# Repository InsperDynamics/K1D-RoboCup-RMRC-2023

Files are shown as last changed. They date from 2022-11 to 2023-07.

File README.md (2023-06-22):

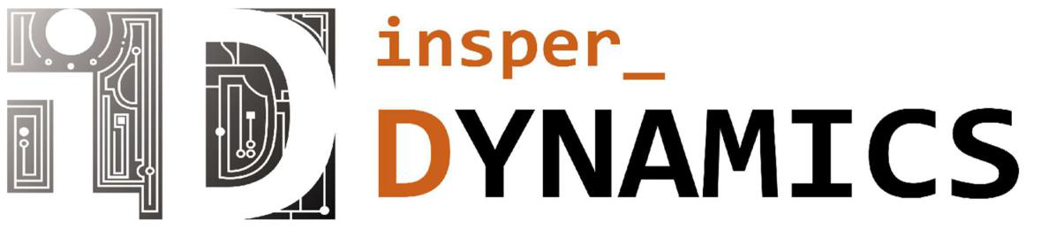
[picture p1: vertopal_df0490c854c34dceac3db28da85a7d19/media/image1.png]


> Team Description Materials\
> Rapidly Manufactured Robot Challenge RoboCup Rescue 2023
>
> Felipe Catapano Emrich Melo, Rafael Eli Katri, Katy Terra, Enricco
> Gemha, Eduardo Mendes Vaz, Paola Friedel

March 2023

 **Abstract**

 The goal of the project presented in this material is the planning,
 construction and testing of a new, semi-autonomous robot suited for
 rescue operations. The robot must be able to traverse heavily uneven
 terrain, inspect the environment and manipulate objects to aid humans
 in dangerous or disaster-related scenarios, where the use of a human
 agent is undesirable or slow.

 It is a major technical overhaul of the project presented by the
 previous team, where more robust mechanical design, manufacturing
 methods, electronics employment and software techniques were used. The
 2023 robot not only takes advantage of previously achieved innovations
 but has improvements in a wide range of aspects that proved to be
 crucial in many scenarios.

 **Introduction**

 The world is constantly evolving, with new and improved solutions
 emerging day by day. A decade ago, self-driving cars were just an
 idea, but now we have cars that are capable of autonomous driving. As
 humans, we are always striving to improve upon existing technology.

 Considering this, RoboCup was established to encourage students in the
 fields of robotics, technology, and AI development to create solutions
 that can benefit humanity.

 One category of the competition is the Rapidly Manufactured Robot
 Challenge, which challenges teams to build smaller and easier to
 produce robots than their Major rescue counterparts, that can assist
 humans in dangerous situations.

 Our team, Insper Dynamics, consisting of five members - Felipe,
 Rafael, Katy, Enrico and Eduardo, are all computer and mechanics
 engineering students from Brazil. With the help of Fabrício Barth, the
 advisor teacher of Insper Dynamics, the team was able to largely
 improve the previous year´s (RoboCup 2022 Thailand) system with the
 use of a simpler and more compact electronic system, aluminum and
 steel parts, flipper tracks, smart servo motors, a web

 interface and algorithm improvements. Our strategies and results are
 detailed in this paper.

 **Structure**

 **Overview**

 The new robot consists of three modular layers. The bottom layer
 contains

two aluminum compartment chassis connected by two bearings and a
pivoting,

machined shaft, as well as four individual flipping track mechanisms.
The middle

 layer is a box with adjustable height, and the top layer has a
 manipulator arm and sensors.

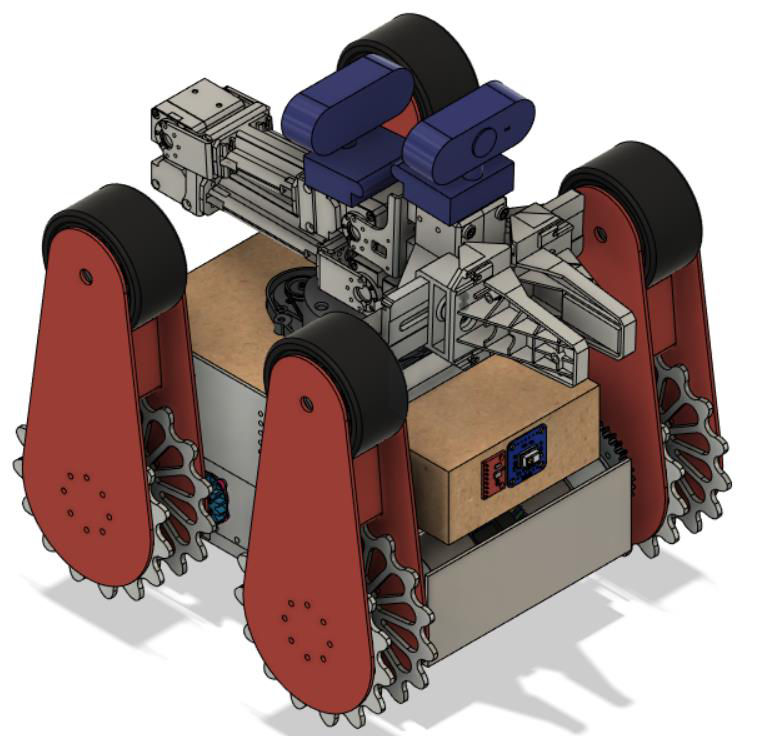
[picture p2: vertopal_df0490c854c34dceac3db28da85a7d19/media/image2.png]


*Figure 1 Isometric view of the robot*

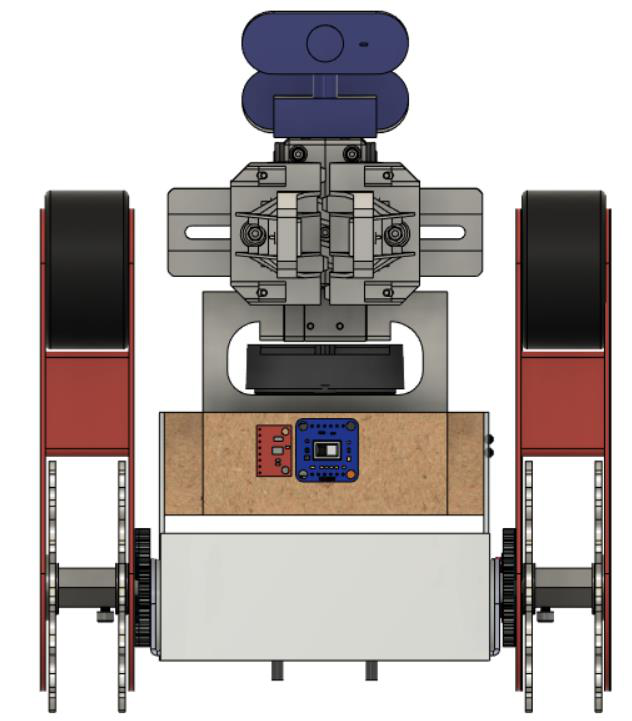
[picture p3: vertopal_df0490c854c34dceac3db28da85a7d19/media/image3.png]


*Figure 2 Frontal view of the robot*

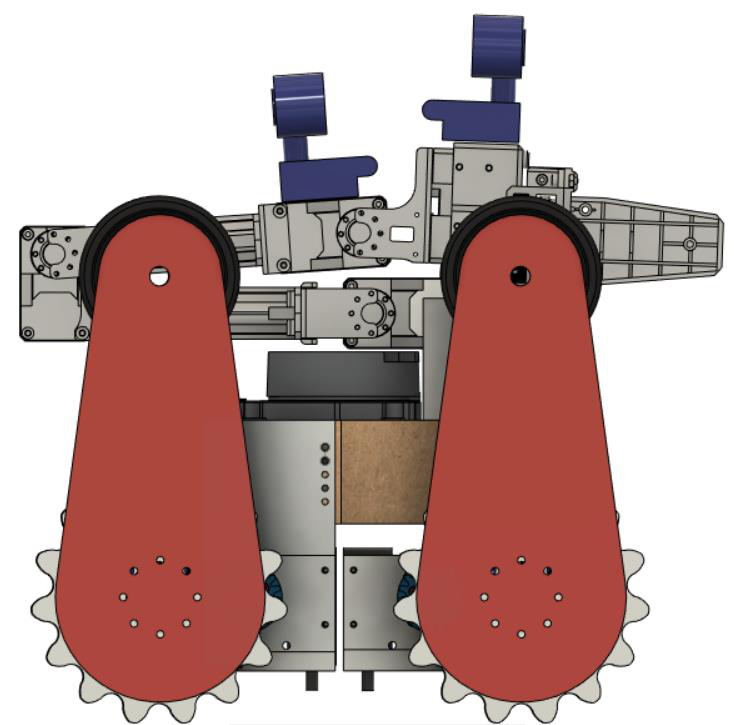
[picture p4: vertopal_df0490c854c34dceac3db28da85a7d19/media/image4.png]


*Figure 3 Side view of the robot*

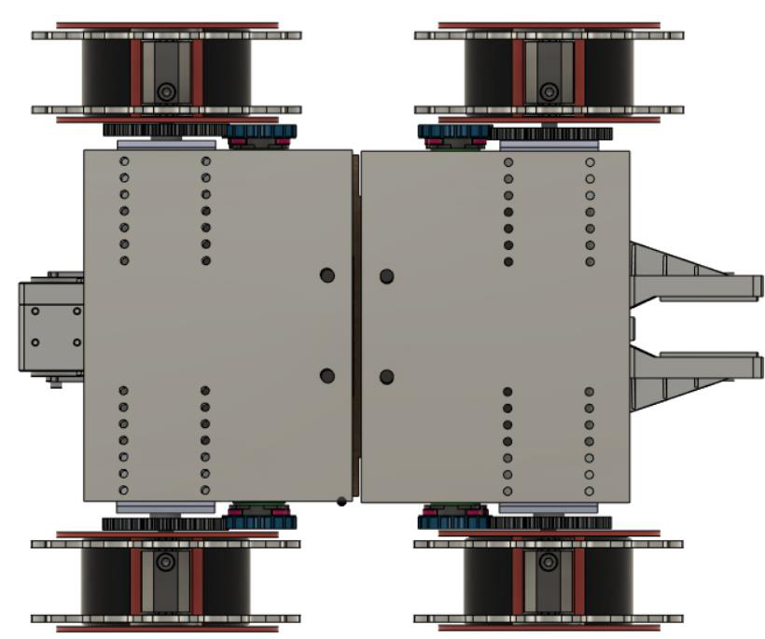
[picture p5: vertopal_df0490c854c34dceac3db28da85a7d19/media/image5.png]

*Figure 4 Bottom vertical view of the robot*

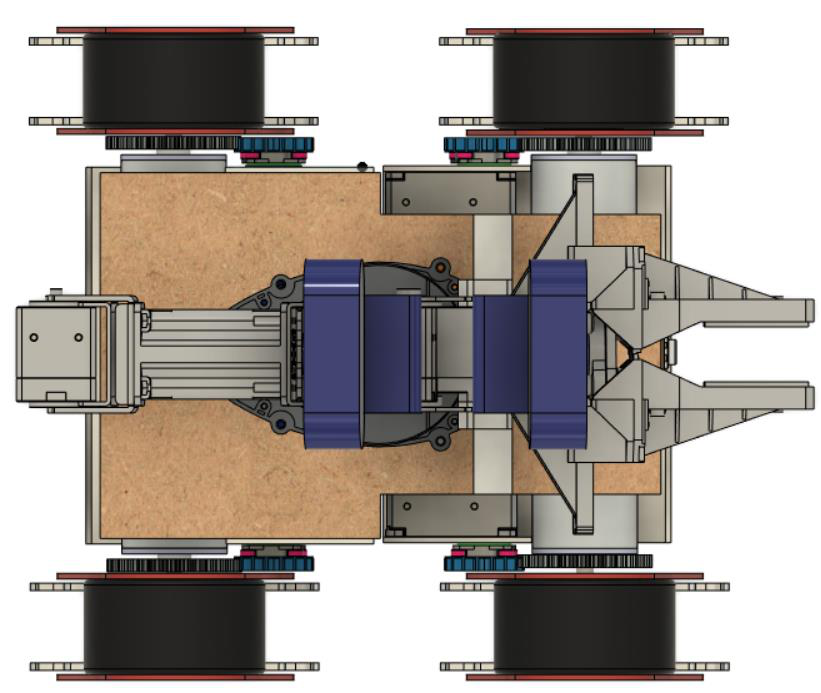
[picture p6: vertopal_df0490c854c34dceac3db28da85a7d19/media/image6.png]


*Figure 5 Top vertical view of the robot.*

 **Metal chassis**

 With the use of a laser or plasma cutter, two low-tolerance parts are extracted from raw material and bent to form housings for two driving DC motors with high torque, two Robotis Dynamixel smart servos, and a bearing holder. This solution is more robust than previous 3D-printed plastic designs, not only due to a better use of available space for mechanical resistance redundancy, but also because of the new material´s tenacity. It also includes a new protection wall against sand, gravel and other sediments that can be harmful to the system.

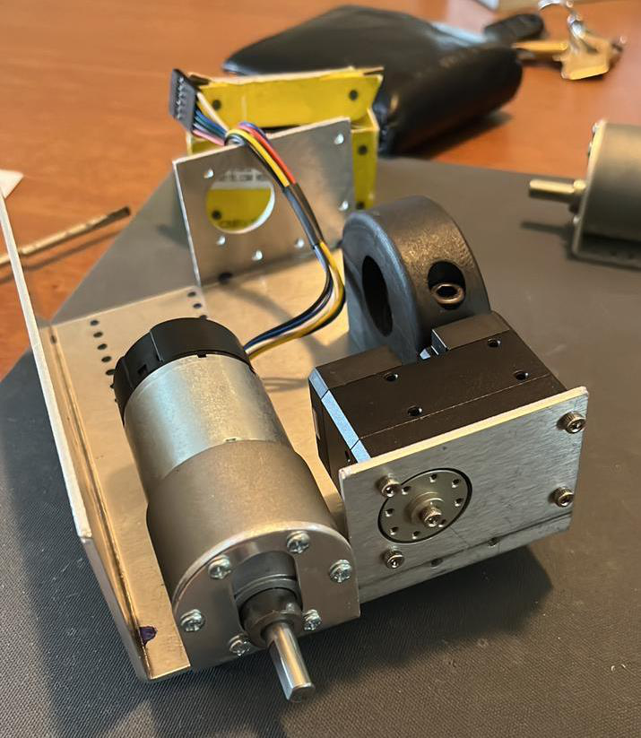
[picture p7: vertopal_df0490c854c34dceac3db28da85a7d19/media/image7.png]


*Figure 6 Half assembly of a chassis compartment*

 The front and back compartments are free to twist around the axis of the central bearings, to act as a passive suspension and allow the robot to always have at least four points of contact with the ground. This was already achieved in the previous project, however this time, a double bearing setup was used with a custom machined shaft. Since a large portion of force is exerted on this central arrangement, this is required to prevent structural failure.

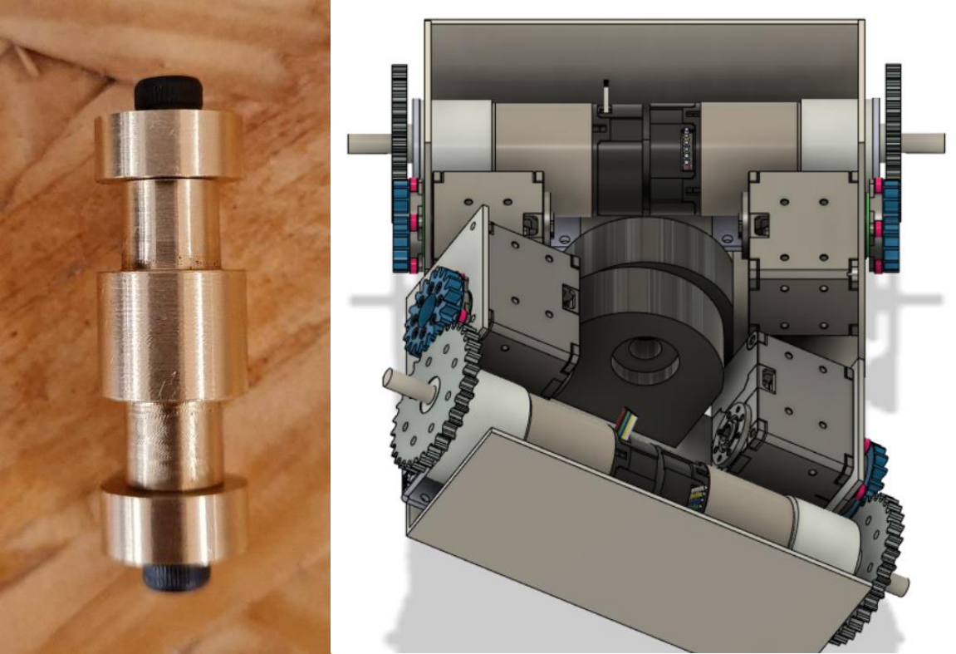
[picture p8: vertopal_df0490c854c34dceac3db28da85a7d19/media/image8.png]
 

*Figure 7 Machined shaft.*

*Figure 8 Demonstration of double-bearing passive suspension*

 **Flipper Tracks**

 Locomotion is achieved with the use of four custom-made tracks arranged in a differential drive setup. Each track can be turned (e.g., "raised" or "lowered") to better accommodate for any terrain, prevent rollovers and overcome higher physical obstacles (such as hurdle pipes in the case of tests proposed by RoboCup).
 This subsystem is composed of:\
 • A flexible, high grip, 40mm rubber track with inner teeth (design
 originally made for use in an industrial machine)\
 • 2 custom-designed aluminum cut crown wheels\
 • A custom-designed aluminum machined shaft for connecting crown wheels.\
 • 2 custom-designed, aluminum cut track faces with bearings • 2 custom-designed, aluminum cut gears\
 • A custom-designed 3D printed track face connector piece.
 • A Robocore Traktor 65mm support wheel with inner bearing

 For the mechanism to work, a primary actuator with high torque output capability (in this case, a 12V-rated Pololu 37D Metal Gearmotor with 70:1 internal gear reduction) is attached to the crown wheel via an axle, while a secondary actuator (Dynamixel XL430-W250-T) with precise position feedback control turns a gear connected to the same axis as
 the primary shaft. When the primary shaft turns, a bearing guarantees that only the crown and track will receive the mechanical transmission. The faces are held in place by the gears, and only turn when the Dynamixel turns.

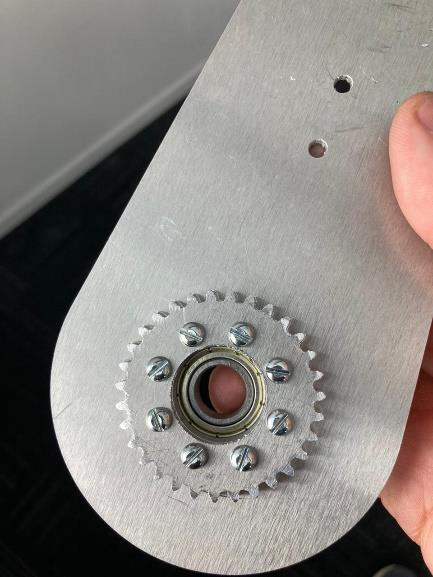
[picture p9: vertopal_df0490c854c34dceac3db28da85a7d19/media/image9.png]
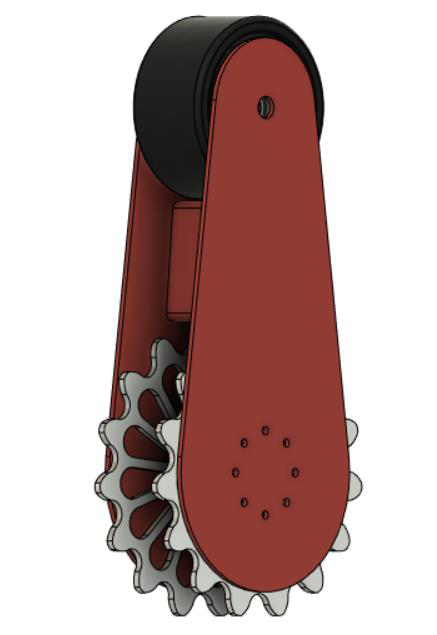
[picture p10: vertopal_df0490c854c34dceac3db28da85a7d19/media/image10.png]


*Figure 9 Track face with bearing.*

*Figure 10 Simplified flipper track (rubber not represented)*

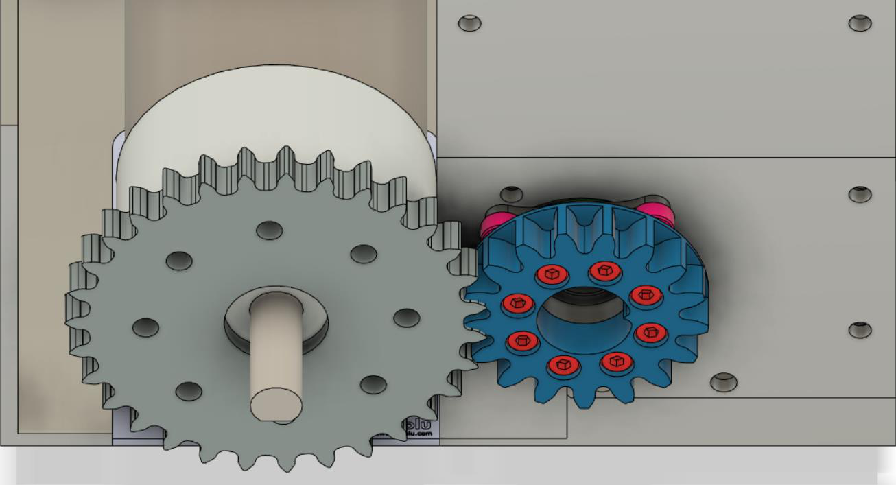
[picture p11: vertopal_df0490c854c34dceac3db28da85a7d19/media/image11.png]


*Figure 11 Dynamixel gear transmission assembly*

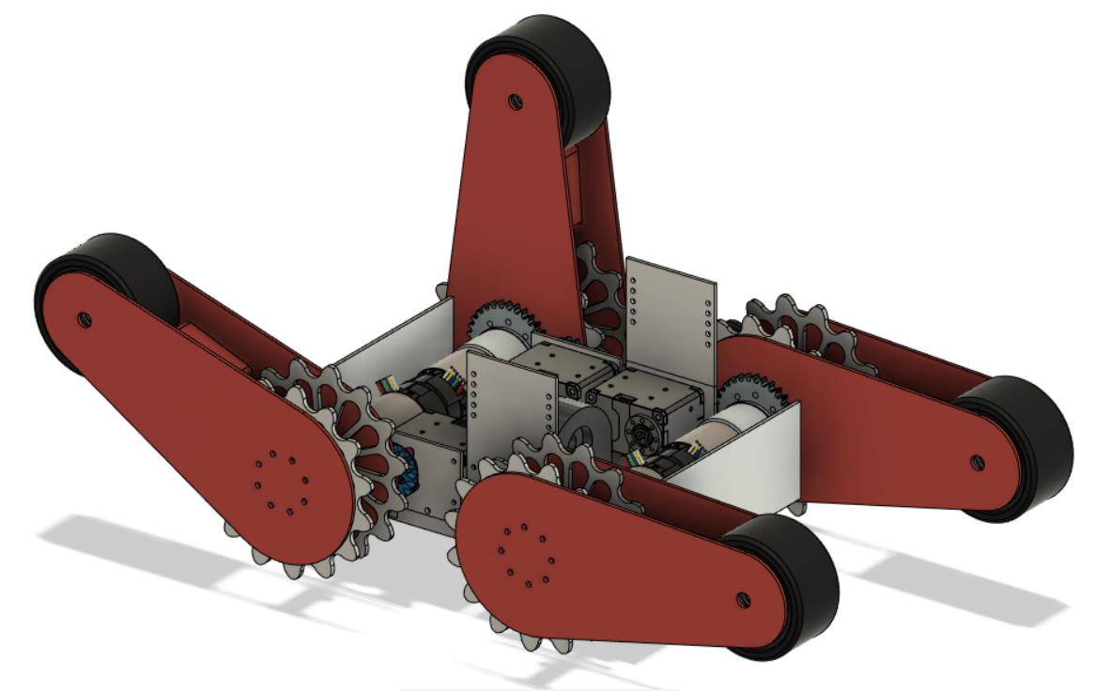
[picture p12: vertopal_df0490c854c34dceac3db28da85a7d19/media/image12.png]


*Figure 12 Since each track can flip individually, many more obstacles
can be overcome*

 **Component Box**

 An intermediate layer in a robot is an essential component that serves
 as a platform for mounting the robot\'s sensors, drivers, and printed
 circuit board (PCB). This layer acts as a bridge between the robot\'s
 control unit and the sensors and actuators, allowing for easy
 communication and control of the robot\'s movements.

 One of the critical features of an intermediate layer is its ability
 to regulate the height of the robot. This allows the robot to operate
 in a variety of environments, including uneven terrain, without
 compromising its stability or accuracy. By adjusting the height, the
 robot can also adapt to different tasks, such as picking up objects of
 varying sizes or navigating through tight spaces.

 In addition to its role in height regulation, the intermediate layer
 also helps to protect the robot\'s sensitive electronic components
 from external factors such as dust, debris, and moisture. By housing
 these components in a secure and protected location, the robot is
 better equipped to operate in challenging conditions and withstand
 wear and tear over time.

 Overall, the intermediate layer plays a crucial role in the
 functioning of a robot, providing a stable platform for the robot\'s
 components while also enabling it to adapt to different environments
 and tasks.

 **OpenMANIPULATOR-X**

 OpenMANIPULATOR-X is an open-hardware arm manipulator developed by
 Robotis. The arm consists of a 5 function and 4 DOF manipulator with 4
 revolution joints and a gripper as an end-effector. OpenMANIPULATOR-X
 has 5 Dynamixel XM430-W350-T actuators, which are set in a daisy
 chain.

 The daisy chain configuration is a significant upgrade to last year\`s
 iteration. As all Dynamixel servos are connected in series, there is
 only one cable to connect to the OpenCR board. Therefore, the robot
 assembly is substantially easier, considering cables of different
 lengths would be otherwise necessary.

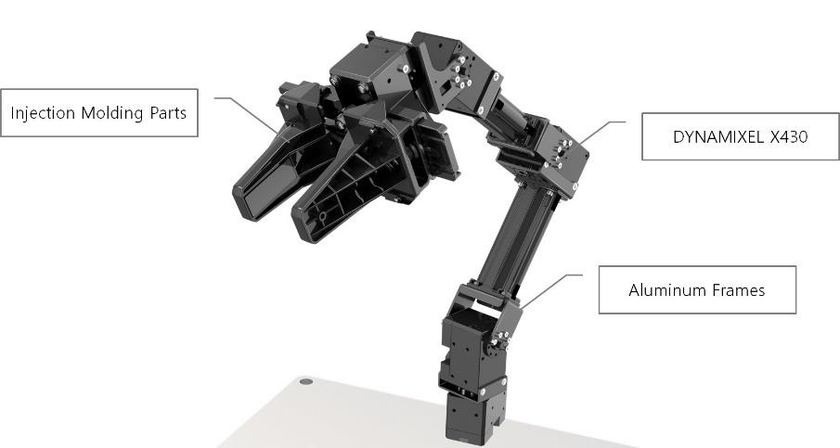
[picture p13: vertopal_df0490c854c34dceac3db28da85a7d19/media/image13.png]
 

*Figure 13 The OpenMANIPULATOR-X robot claw*

 The Dynamixel actuators have RAM and EEPROM control tables that are
 used to set position goals and get joint position, velocity, and
 effort data. To establish communication to the OpenCR, a TTL serial
 connector is connected from the daisy chain to the board and
 information is shared via the Dynamixel Protocol 2.0. To handle this
 exchange in a higher level, the Dynamixel Workbench library is used.
 This a remarkable upgrade, considering that the last iteration could
 only use current goals via PWM and there was a need to use extra
 components to regulate the voltage.

 **Electronics**

 **OpenCR**

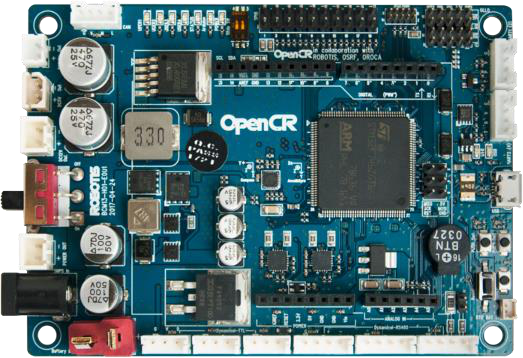
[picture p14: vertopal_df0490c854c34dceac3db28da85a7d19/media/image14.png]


*Figure 14 Robotis OpenCR Board*

 Electronics and decision-making play an integral role in the operation
 of robots. With advancements in technology, robots have become
 increasingly sophisticated, relying on a combination of hardware and
 software to execute tasks. In the past, robots were designed to carry
 out most of the processing on their own, with a computer used solely
 for commanding and monitoring the robot\'s actions. However, with the
 evolution of technology, this paradigm has shifted, with robots now
 requiring a more powerful computer to perform complex computations.

 One example of this shift is the use of the OpenCR board, which is
 like an Arduino board but specifically designed to support Dynamixel
 servos. The OpenCR board provides a powerful and flexible platform for
 controlling the servos, allowing for precise and reliable movements.
 By offloading the processing of the servos to the OpenCR board, the
 robot\'s main computer can focus on other tasks, such as sensor data
 processing, decision-making, and high-level control.

 Furthermore, the ability to make quick and accurate decisions is
 critical in robotics, particularly in situations where the robot needs
 to respond quickly to changes in the environment. With the OpenCR
 board, the robot can make decisions faster, reducing the delay between
 sensing and acting. The use of advanced algorithms, such as machine
 learning and artificial intelligence, can further enhance the robot\'s
 decision-making capabilities, enabling it to adapt to changing
 conditions and learn from experience.

 In summary, the integration of electronics and decision-making plays a
 crucial role in the operation of robots. The use of specialized
 hardware, such as the OpenCR board, and advanced algorithms, allows
 robots to make decisions quickly and accurately, increasing their
 ability to perform complex tasks. As technology continues to evolve,
 we can expect to see even more sophisticated robots, capable of
 performing tasks that were once thought impossible.

 **DC Motor Drivers**

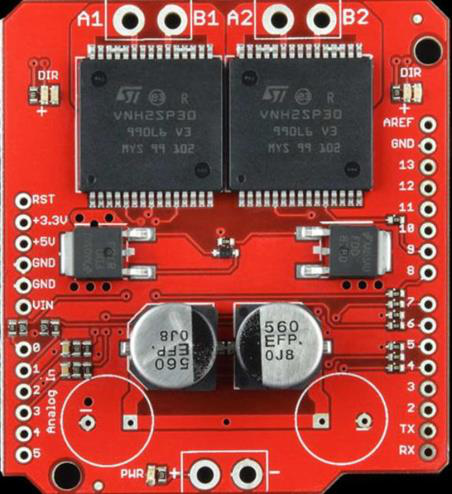
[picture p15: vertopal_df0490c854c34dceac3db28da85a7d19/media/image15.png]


*Figure 15 VNH2SP30 Dual Motor Shield*

 To drive the DC motors in the robot, two VNH2SP30 Dual Drivers are
 used.

 They are the same drivers used in the previous project.

 Since cheap drivers are not energetically efficient, we use this
 driver that can control 2 DC motors, with a maximum current draw of
 30A for each channel.

 This motor drive uses the following ports to control the motors: -
 Digital 4: InputB from motor 1\
 - Digital 5: PWM from motor 1\
 - Digital 6: PWM from motor 2\
 - Digital 7: InputA from motor 1\
 - Digital 8: InputA from motor 2\
 - Digital 9: InputB from motor 2\
 - Analogic 0: Enable from motor 1\
 - Analogic 1: Enable from motor 2

 The logic for VNH2SP30 usage is the same as for L298n drivers, the only difference being the enable pins, which need to be driven HIGH to work.

 **PCB**

 Printed circuit boards (PCBs) are critical components in the design
 and manufacturing of electronic devices, including robots. The latest
 version of our PCB has been specifically designed to support the
 OpenCR driver, which is a

 powerful and flexible platform for controlling Dynamixel servos. This
 integration allows for precise and reliable movement control, ensuring
 that your robot can execute tasks with accuracy and consistency.

 In addition to supporting the OpenCR driver, we also removed the
 step-down circuit from the latest version of the PCB.

 It is important to note that while the actual version of our PCB is
 very similar to the latest version, the addition of support for the
 OpenCR driver and the removal of the step-down circuit represent
 significant changes that can impact the robot\'s performance and
 functionality.

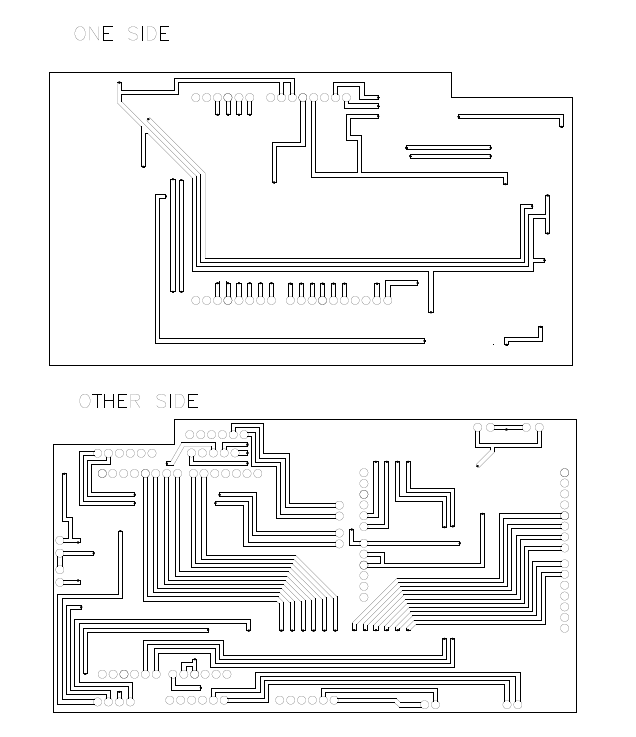
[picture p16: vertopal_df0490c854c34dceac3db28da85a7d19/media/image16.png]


*Figure 16 Both sides of PCB*

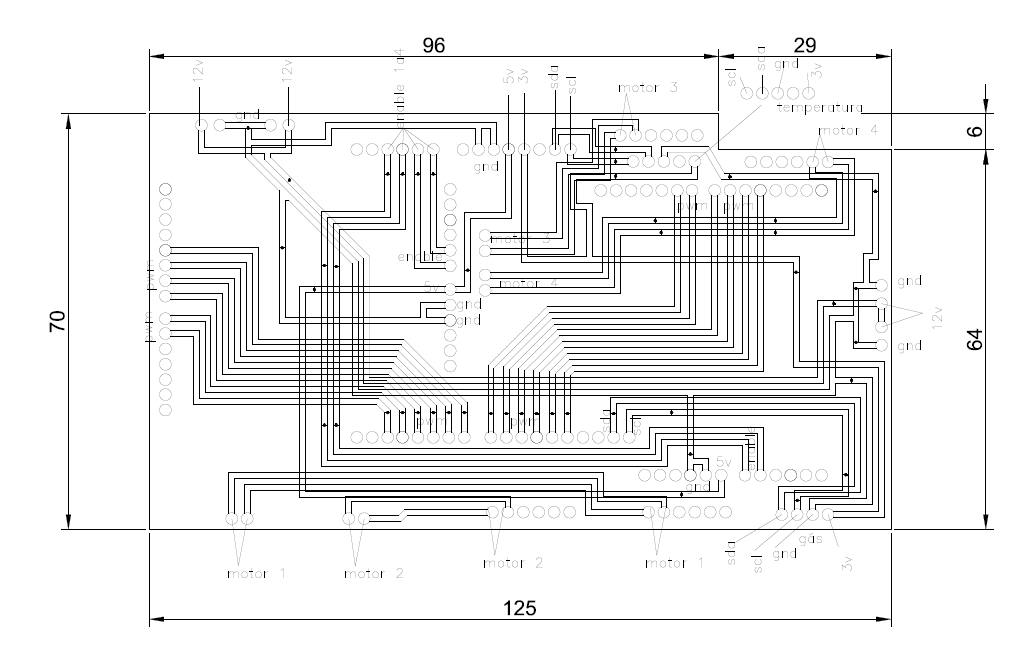
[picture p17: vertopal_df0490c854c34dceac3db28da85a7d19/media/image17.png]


*Figure 17 Dimensions of PCB*

 **Lidar Scanner**

 Lidar LDS01, also known as the Hokuyo URG-04LX-UG01, is a popular
 laser rangefinder sensor used in robotics. Its widespread use can be
 attributed to its ease of use and programmability. The sensor is
 commonly used in robots such as the TurtleBot, where it serves as a
 key component for obstacle avoidance and navigation.

 One of the main advantages of Lidar LDS01 is its plug-and-play
 functionality. The sensor comes with a USB interface that can be
 easily connected to a computer or a microcontroller. Additionally,
 there is no need for any additional drivers or software installation,
 which makes it a hassle-free solution for beginners and professionals
 alike. The sensor can be programmed using various programming
 languages such as Python and C++, making it a versatile choice for
 different projects.

 The Lidar LDS01 sensor provides accurate and reliable distance
 measurements, with a range of up to 4 meters and a resolution of 1mm.
 It has a scanning frequency of 10 Hz, making it suitable for real-time
 applications. The sensor is also lightweight and compact, which makes
 it easy to mount on robots or mobile platforms.

 One of the notable applications of Lidar LDS01 is in the field of
 autonomous navigation. With its high accuracy and resolution, the
 sensor can be used to create 2D maps of the environment, which can
 then be used by the robot for path planning and obstacle avoidance.
 The sensor\'s scanning frequency and range make it suitable for both
 indoor and outdoor applications.

 In conclusion, Lidar LDS01 is a reliable and easy-to-use sensor that
 has become a popular choice for robotics applications. Its
 plug-and-play functionality, programmability, and accuracy make it an
 excellent option for both beginners and professionals. The sensor\'s
 compact size and light weight make it easy to integrate into different
 robotic platforms, and its high scanning frequency and range make it
 ideal for real-time applications. With its numerous benefits, Lidar
 LDS01 is undoubtedly an excellent choice for anyone looking for a
 dependable and versatile laser rangefinder sensor for their robotics
 projects.

 **Cameras**

 Cameras are a crucial component in our robot, enabling us to perceive
 and interact with our environment. We are using high-resolution
 generic cameras to capture images and video of the environment. These
 cameras are mounted on our robot arm and equipped with fisheye lenses
 to capture a wider field of view.

 The cameras we are using have a high resolution, allowing for detailed
 and accurate image capture. This is particularly important in robotics
 applications where visual perception is critical, such as object
 recognition, navigation, and

 mapping. The high-resolution cameras also allow for better accuracy
 and precision in the manipulation and control of objects in the
 environment.

 By mounting the cameras on our robot arm, we can capture images from
 different angles and positions, providing a more comprehensive view of
 the environment. This is particularly useful in applications such as
 object recognition and tracking, where the ability to capture images
 from multiple angles can improve the accuracy and robustness of the
 system.

 The fisheye lenses we are using provide a wide-angle view of the
 environment, enabling our robot to capture a broader field of view.
 This is particularly useful in applications where our robot needs to
 navigate in complex and dynamic environments. The fisheye lenses also
 allow for the capture of 360-degree panoramic images, which can be
 useful for mapping and visualization applications.

 **Thermal Imager**

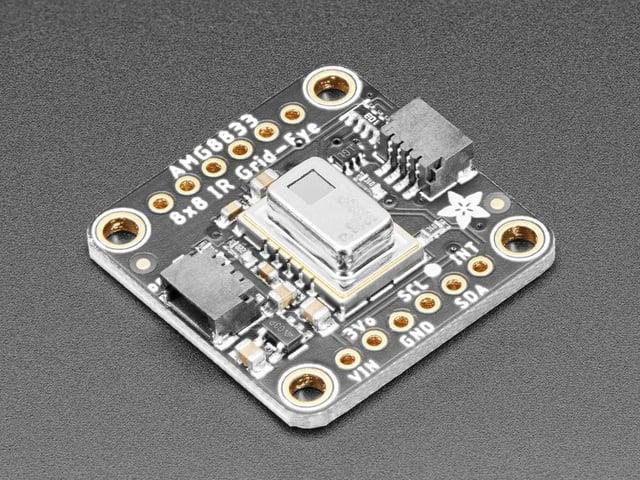
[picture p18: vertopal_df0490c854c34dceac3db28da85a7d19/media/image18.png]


*Figure 18 AMG8833 8x8 Thermal Imager Module*

 The thermal imager that we are using is the AMG8831, which has support for Arduino, Raspberry Pi and any other device that can communicate over I2C. This electronic module has and high efficiency and is based on Infrared heat detection sensor that allows the user to detect movement in dark environments, for example.

 This sensor has a matrix of 8x8 thermal sensors and returns a matrixof 64 temperature individual readings. In the previous year, the team has studied the possibility of acquiring a new camera with a higher resolution, which in a real rescue scenario would provide better readings for the operator. Since this factor is not considered in RMRC,however, the team decided to remain with the 8x8 camera to reduce costs of the project.

 **CO2 Measurement Sensor**

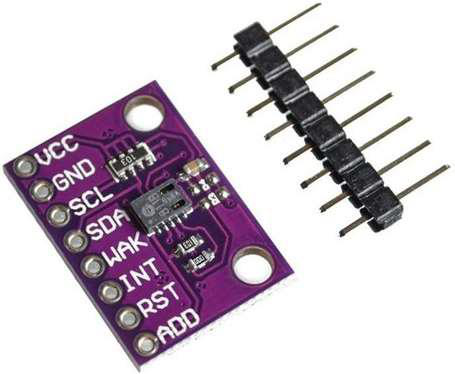
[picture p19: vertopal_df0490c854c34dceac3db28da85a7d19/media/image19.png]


*Figure 19 CCS811 Sensor*

 The CCS811 is a low power miniature digital gas sensor for monitoring
 air quality. A metal oxide sensor is integrated to measure the total
 volatile organic compounds equivalent of TVOCs, making it possible to
 monitor air quality when working in conjunction with microcontrollers,
 only requiring I2C serial communication.

 The module is based on unique microplate technology, meaning the plate
 presents a highly reliable solution for projects that require gas
 sensor, fast cycle times and a significant reduction in average power
 consumption. The integrated MCU manages the sensor trigger modes and
 the measured data. The CCS811 supports intelligent algorithms to process measurements and output an equivalent TVOC value, as well as supporting multiple measurement modes that are optimized for low power consumption, thus extending battery life in portable devices.

 It also requires 3.3 V which comes from Arduino. The pins from CLOCK and DATA (SCL and SDA) are connected in series with the same pins from the thermal camera, and them connected on Arduino's I2C pins.

 Learn more at: https://www.sparkfun.com/products/14193 .

 **Software**

 **ROS**

 ROS (Robot Operating System) is an open-source software framework used
 to develop and control robotic systems. It provides a collection of
 tools, libraries, and conventions for creating complex and robust
 robot applications. ROS offers a distributed computing environment
 that allows multiple processes to run simultaneously on different
 machines and communicate with each other through messages. It also
 includes various components such as drivers that enable developers to
 easily integrate and control hardware components.

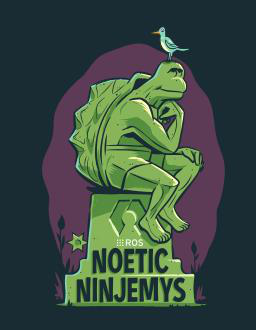
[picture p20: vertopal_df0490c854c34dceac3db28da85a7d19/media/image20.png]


 *Figure 20 ROS Noetic*\
 For this year\'s iteration ROS Noetic, the latest long term support
 ROS 1 distro, was chosen. The main changes from this version include
 Python 3 support and performance improvements of real-time operations
 and memory management. The framework is used in the project primarily
 for communicating data between the master and slave processes. In
 addition, ROS packages such as *"hector slam"* and *"gmapping"* are
 used for autonomous navigation and *"hls_lfcd_lds_driver"* is a ROS
 wrapper that controls the LDS-01 lidar.

 Another major difference is that the master process, responsible for
 the machine vision algorithms, handling controller input and sharing
 sensor data to the interface, runs on an external computer. This
 implies in a more reliable power supply to the master process, which
 is also safe from wall collisions.

 With the use of roslibjs, a JavaScript library that allows interaction
 with ROS data via browser, a new user interface was developed, in
 contrast to last

 year\`s version, that was part of the main software executable, this
 interface is self-dependent. The communication is based on WebSockets
 and the *"rosbridge"*package.

 **MoveIt**

 MoveIt is an open-source software framework for motion planning and
 manipulation of articulated robots, including robot arms and grippers.
 It provides a set of tools, libraries, and APIs that enable developers
 to plan, execute, and visualize robot motions in real-time. MoveIt
 includes various algorithms for motion planning, collision detection,
 trajectory generation, and kinematics.

 Robotis, the company that developed the Open-Manipulator-X robot arm,
 has a ROS environment that allows to create trajectories and control
 the arm\`s actuators. Nevertheless, this method proved to be
 unreliable as the program consistently freezes and miscalculate
 trajectories. The out-of-the box experience for Open-Manipulator-X was
 lacking, so MoveIt was chosen as a more robust and complete
 alternative.

 The framework\`s *"move_group"* API is used to plan
 Open-Manipulator\`s trajectory. The API uses ROS topics as endpoints
 to get goals on task or joint space and calculates the trajectory
 using forward and inverse kinematic equations. Description files as
 URDF and SRDF, that describe the claw\`s dimensions and information
 relative to joints and mechanical behavior, are used to setup MoveIt
 configuration and the *"move_group"* API.

 The actuators are controlled on the slave process and joint position
 data is constantly updated by the OpenCR and shared via ROS to the
 joint state topic, which is subscribed by the *"move_group"* API. The
 low-level controller has a layer of abstraction to integrate to
 MoveIt, using ROS topics.

 **React Interface**

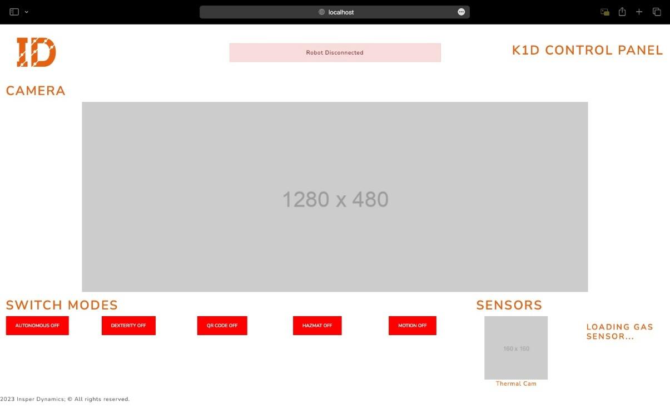
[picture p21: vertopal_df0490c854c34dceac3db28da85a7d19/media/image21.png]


*Figure 20 New robot interface*

 On the front-end, the interface was designed using the application, as
 seen in Figure 20, so that it followed a fixed UI/UX pattern and
 provided the best usability experience for the robot pilot. The idea
 was to bring all the information (camera image, sensor data, \...)
 directly to the point and make the buttons as intuitive as possible,
 such as with their color in red when a certain robot mode is inactive,
 and green when active. The images that can be seen in Figure 20 on the
 interface are placeholders used when the robot is not connected, still
 maintaining the previously established layout pattern. a JavaScript
 framework, was used to create the interface.

 On the back-end (if it can be called that, because we did not use a
 database), the library was used in JavaScript, which is part of the
 ROS ecosystem (via a websocket called ), so that the buttons can
 publish information on their respective topics, and the camera images
 and sensor information can be obtained by subscribing to the desired
 topic. For this communication to have a real-time factor, the use of
 React was very important, as any change of state in the topics
 reflects an immediate change in the visual

 feedback of the interface, without any delay or bottleneck. To better
 understand what the publishers and subscribers are, see Figure 21 and
 22.

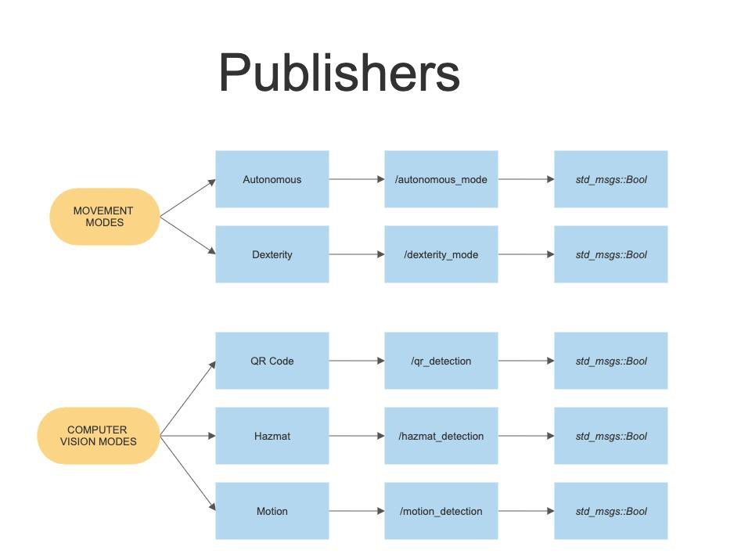
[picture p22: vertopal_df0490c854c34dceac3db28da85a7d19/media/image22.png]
 

*Figure 21 Interface Publisher Topics*

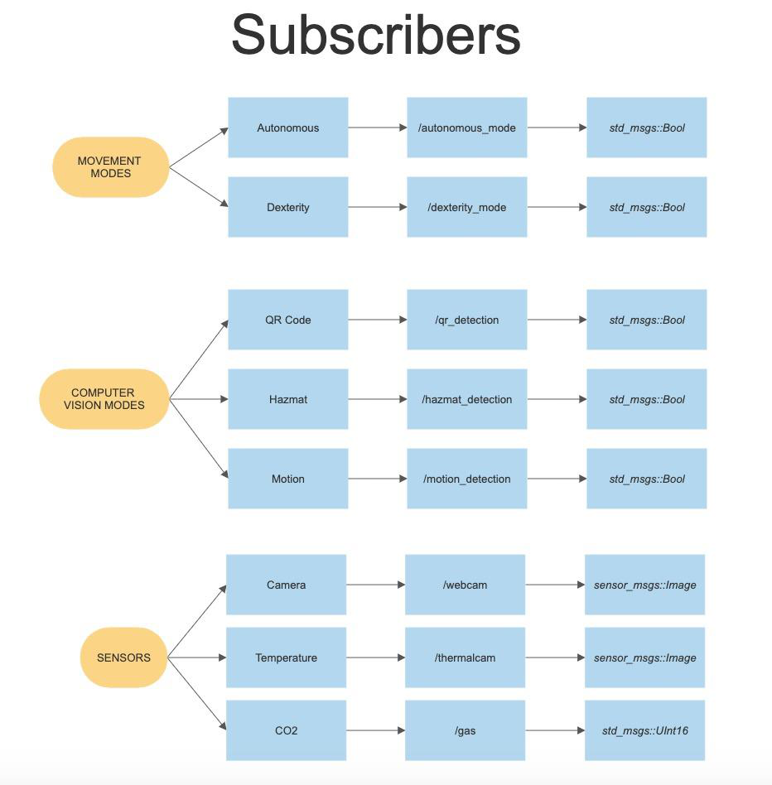
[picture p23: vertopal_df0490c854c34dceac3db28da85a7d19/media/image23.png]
 

*Figure 22 Interface Subscriber Topics*

 **YOLOv5**

 In order to enable the robot to quickly and reliably detect Hazmat
 Labels, a new custom object recognition model was created. This time, utilizing a larger labeled image dataset and a faster implementation of the YOLO real-time object detection algorithm (v5 compared to previously used v3).

 The algorithm uses features learned from a deep convolutional neural
 network in a supervised training process. Because of the grid-based
 probabilistic approach, multi-class detection with vector
 generalization is achieved, and all kinds of hazmat signs can be
 detected regardless of translation or rotation in the image, or any
 external factors such as brightness, saturation, background, etc. Such
 factors contributed for the popularization of this algorithm, which
 is, as of right now, considered a state-of-the-art approach to solving
 object recognition problems.

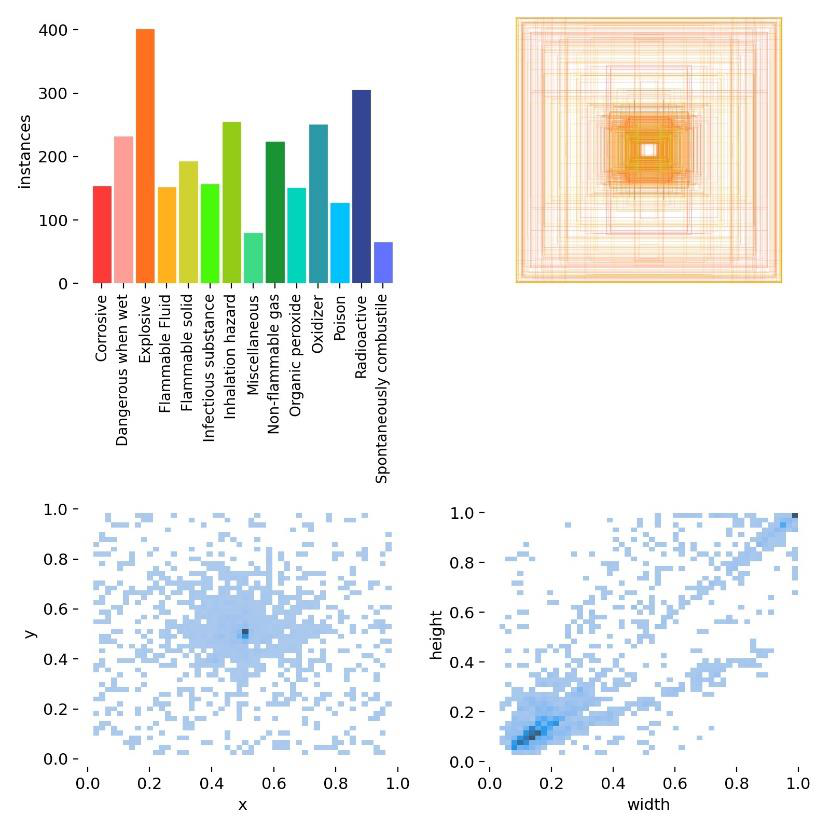
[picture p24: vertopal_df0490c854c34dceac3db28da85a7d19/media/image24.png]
 

*Figure 23 Hazmat dataset label statistics*

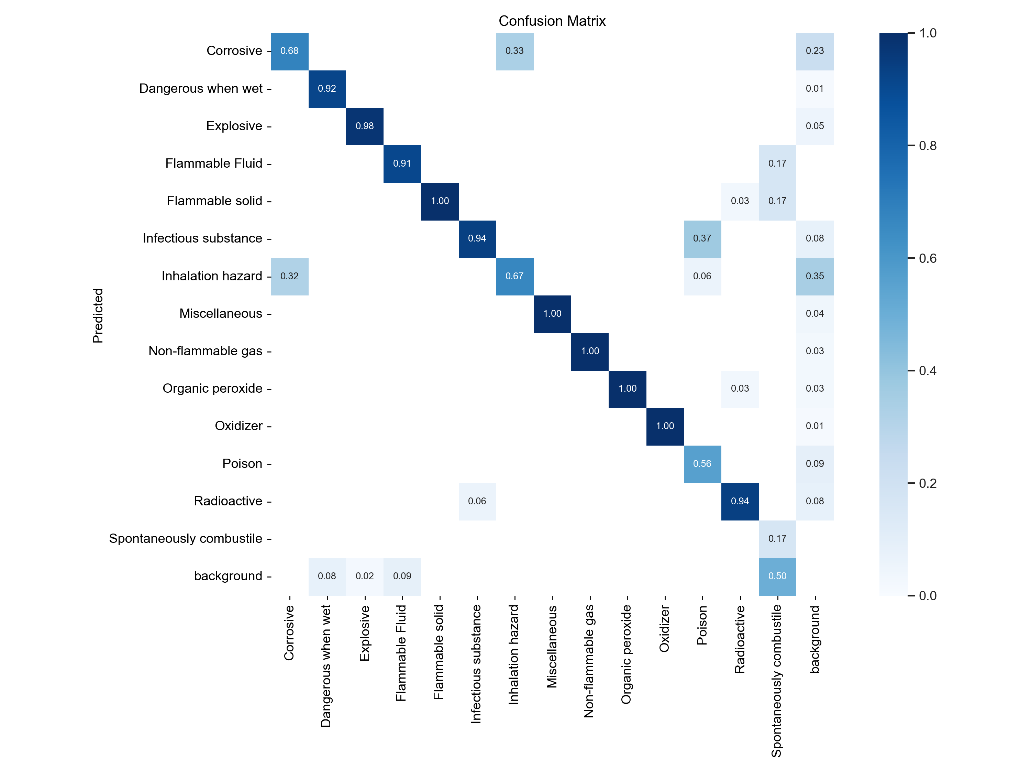
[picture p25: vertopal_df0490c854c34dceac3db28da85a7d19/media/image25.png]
 

*Figure 24 YOLOv5 model confusion matrix*

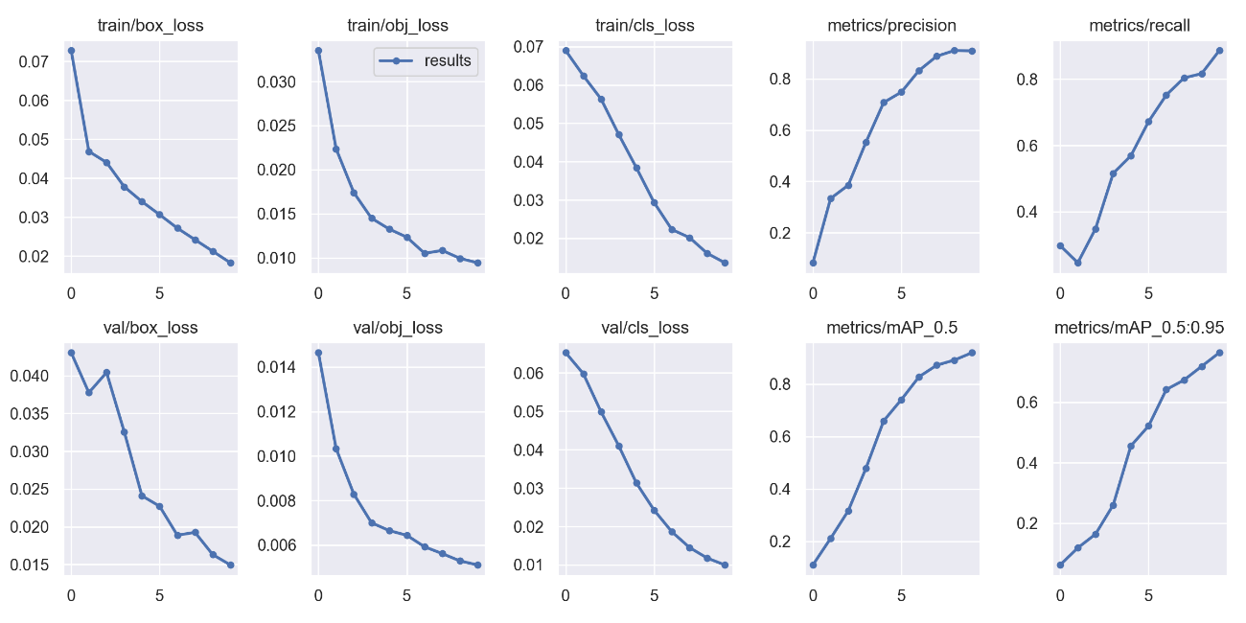
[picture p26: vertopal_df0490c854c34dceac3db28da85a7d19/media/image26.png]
 

*Figure 25 YOLOv5 model training results*

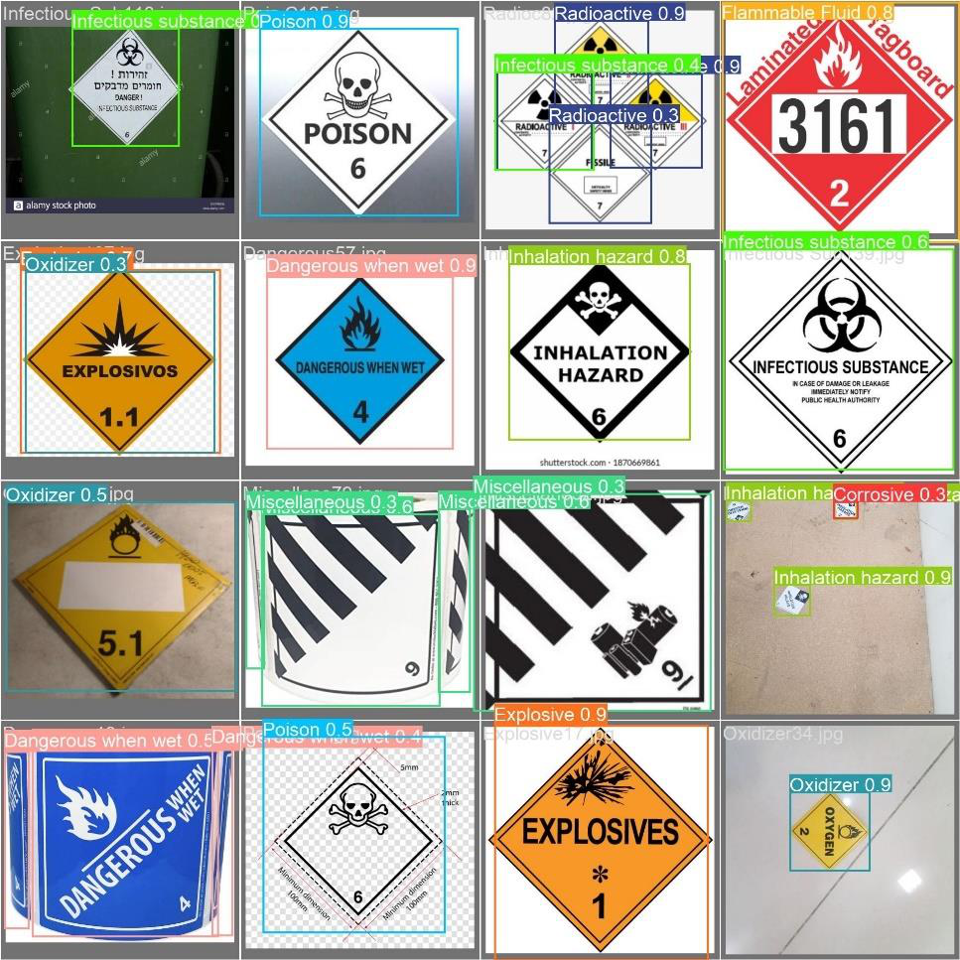
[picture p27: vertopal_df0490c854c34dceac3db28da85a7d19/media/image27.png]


*Figure 26 YOLOv5 model prediction example*

 It is worth stating, however, that QR Detection on the robot is not
 achieved via the use of a YOLO model. For this specific task, the ZBar
 C++ library is used. This algorithm has very similar performance
 characteristics and has been proven by the team to be capable of
 reliably detecting and decoding QR Codes in real-time, through
 extensive testing in a variety of situations.

 **SLAM and Autonomous Navigation**

 Simultaneous Localization and Mapping (SLAM) is a task that consists
 of tracking an agent location in a procedurally generated map, which
 is created by the agent\`s sensors. In this year\`s iteration, the
 *"hector slam"* ROS package gathers the LDS-01 laser scan data and
 generates a two-dimensional occupancy grid to map the robot\`s
 surroundings.

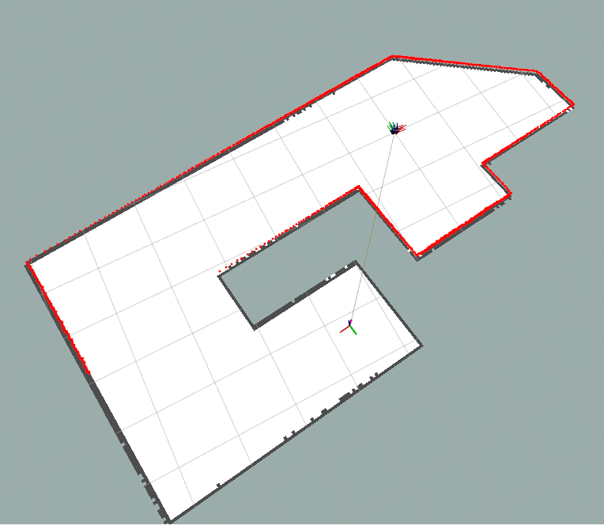
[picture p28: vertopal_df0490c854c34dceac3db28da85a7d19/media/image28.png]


*Figure 27 Occupancy Grid example*

 The autonomous navigation algorithm passed through major changes to be
 optimized to small areas. Tailored with the preliminaries and
 best-in-class phases in mind, the algorithm consists of collecting
 laser scan data to identify the distances of the robot to the walls
 and ensuring it is centralized on the course. This stems from previous
 experiences, in which frontier exploration and more complex path
 planning algorithms were not efficient on small areas with known
 shape. Even though its principle is rather simple, the autonomous
 algorithm is faster and more reliable than its predecessor.

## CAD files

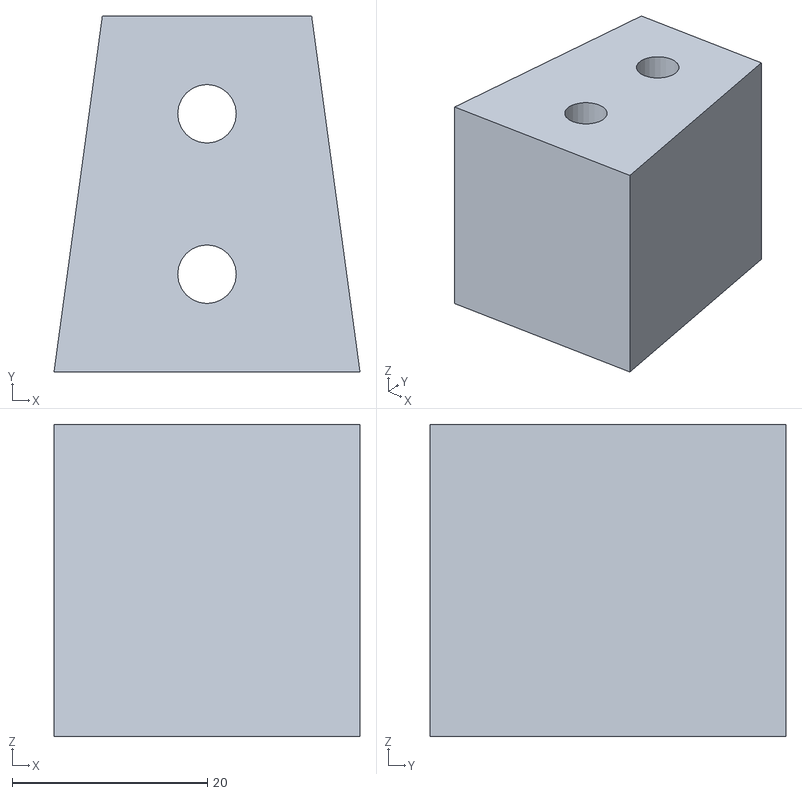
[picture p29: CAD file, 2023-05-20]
3D models and Schematics/3D models to print/ThreadSupport_spreader.stl
31.3 x 36.4 x 32.0

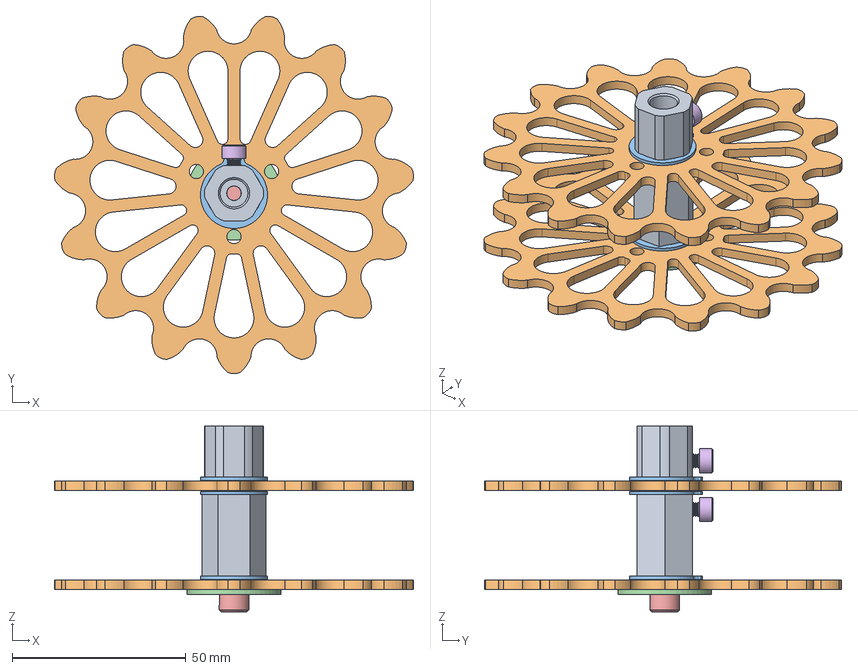
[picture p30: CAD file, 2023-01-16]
3D models and Schematics/Components (used for reference)/Traktor Crown.step
103.4 x 102.9 x 53.5 mm
Cubo5-8pol-eixo8mm_Predeterminada
Coroa-15dentes_Predeterminada x 2
basic external retaining ring_am_B27.7M - 3AM1-17 x 3
Arruela_Funileiro_3-16pol_Predeterminada
socket head cap screw_am_B18.3.1M - 5 x 0.8 x 12 Hex SHCS -- 12SHX
socket head cap screw_am_B18.3.1M - 4 x 0.7 x 6 Hex SHCS -- 6SHX x 2

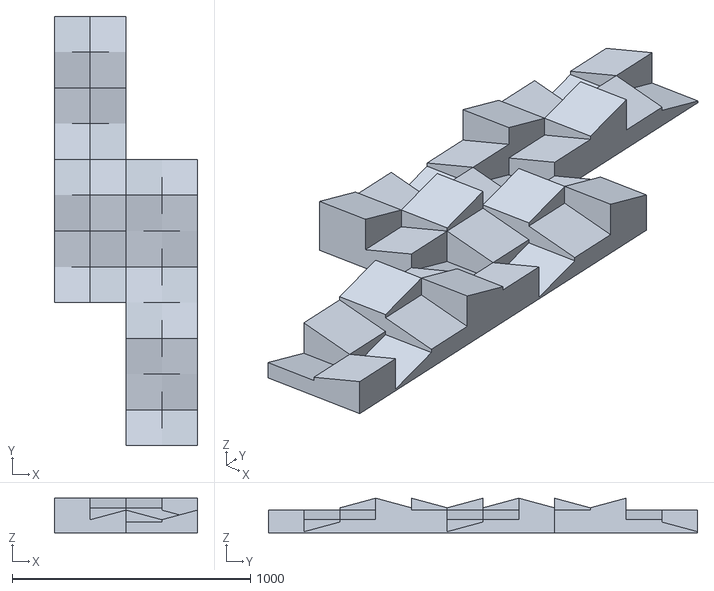
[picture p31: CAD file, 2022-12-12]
Arena/Elevated_ramps_floor.stl
600.0 x 1800.0 x 145.4

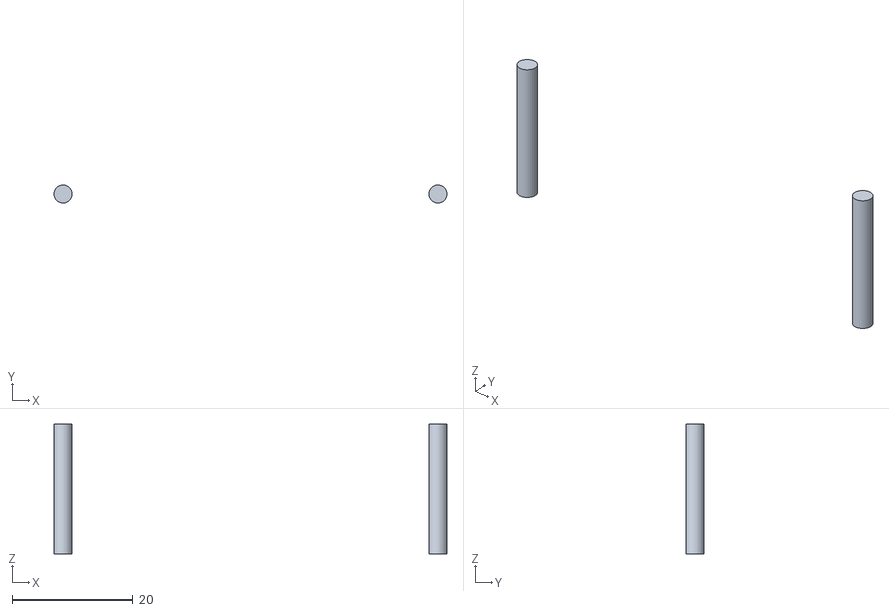
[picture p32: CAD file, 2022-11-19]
ROS/k1d_description/meshes/spacer_1.stl
65.0 x 2.98 x 21.5

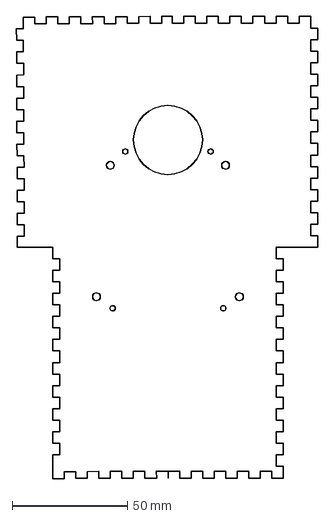
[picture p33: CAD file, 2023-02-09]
3D models and Schematics/3D models to print/mdf_top.dxf
130.6 x 200.5 mm

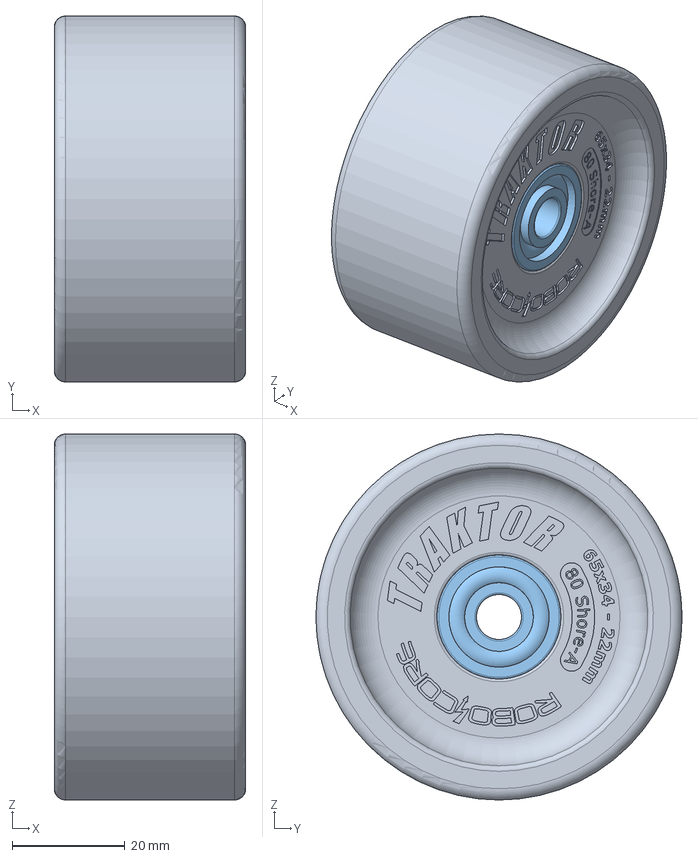
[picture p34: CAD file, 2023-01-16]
3D models and Schematics/Components (used for reference)/Traktor support_wheel.step
34.0 x 65.0 x 65.0 mm
Rodizio-POM_Usinado_Predeterminada
Espacador-10mm_Predeterminada
radial ball bearing_68_din_DIN 625 - 608 - 8,SI,NC,8_68 x 2

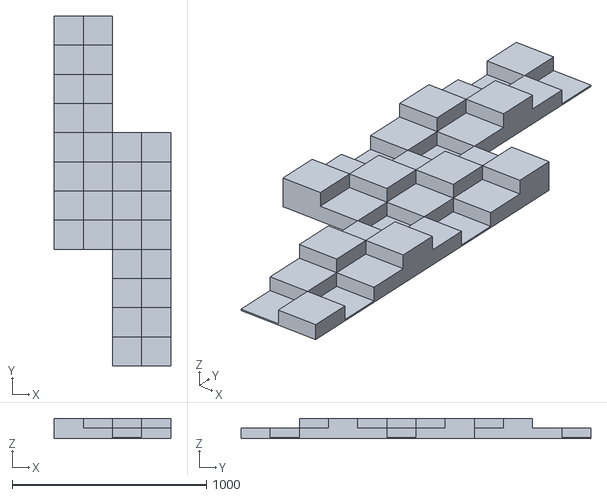
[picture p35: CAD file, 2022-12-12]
Arena/Stepfields_floor.stl
600.0 x 1800.0 x 105.0

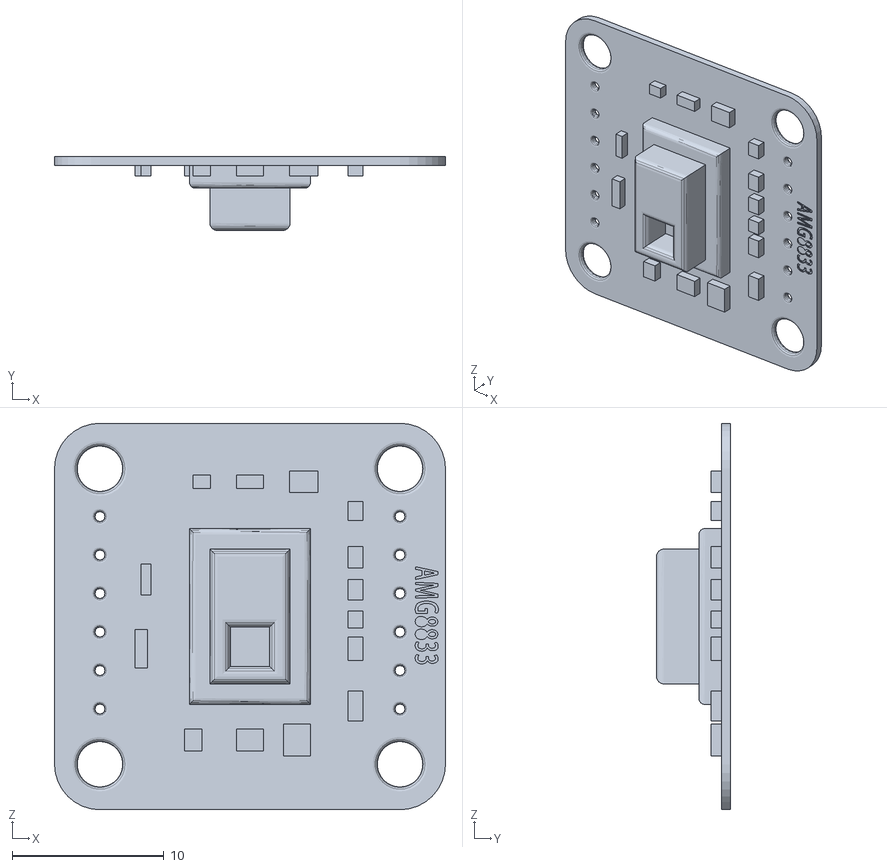
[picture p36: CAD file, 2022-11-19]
ROS/k1d_description/meshes/thermalsensor_1.stl
25.8 x 4.90 x 25.5

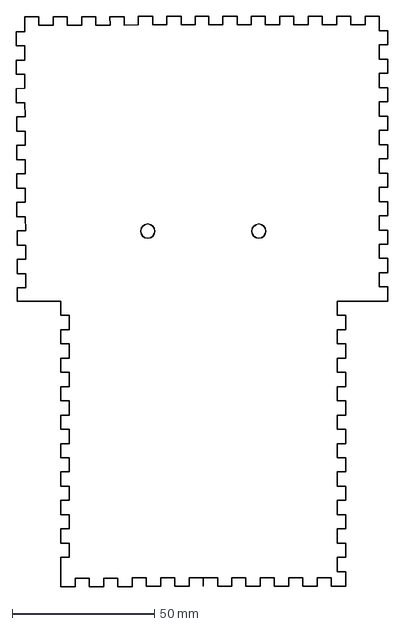
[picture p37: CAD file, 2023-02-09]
3D models and Schematics/3D models to print/mdf_bottom.dxf
130.6 x 200.5 mm

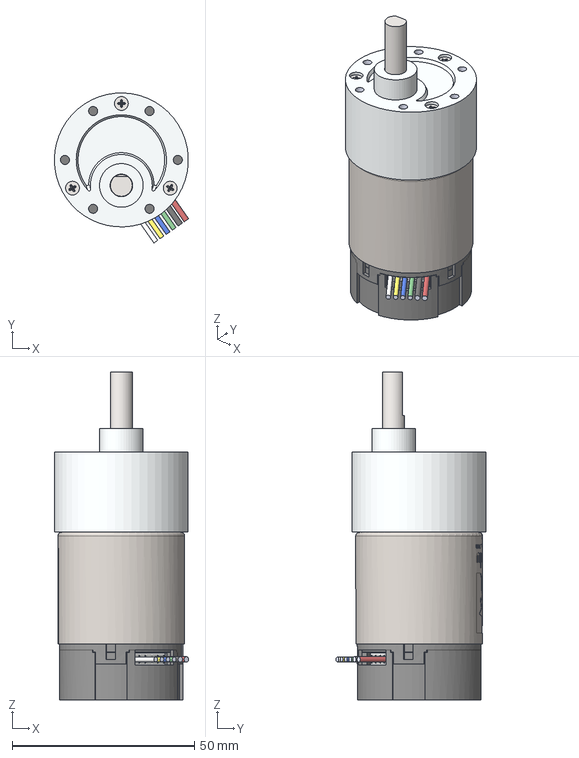
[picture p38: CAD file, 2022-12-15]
3D models and Schematics/Components (used for reference)/Motor.step
36.9 x 41.2 x 90.1 mm

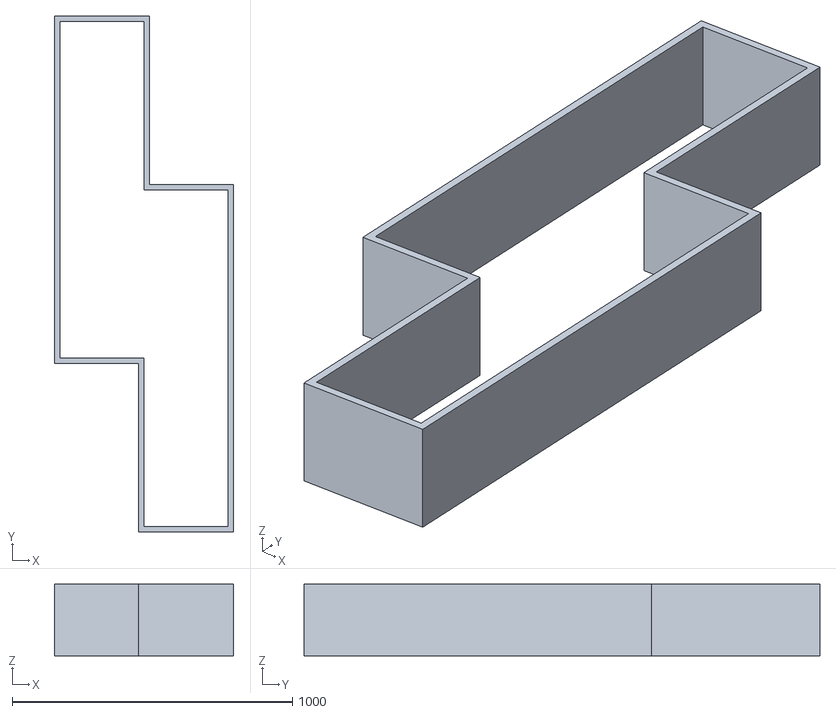
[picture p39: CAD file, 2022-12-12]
Arena/walls.stl
640.0 x 1840.0 x 255.0

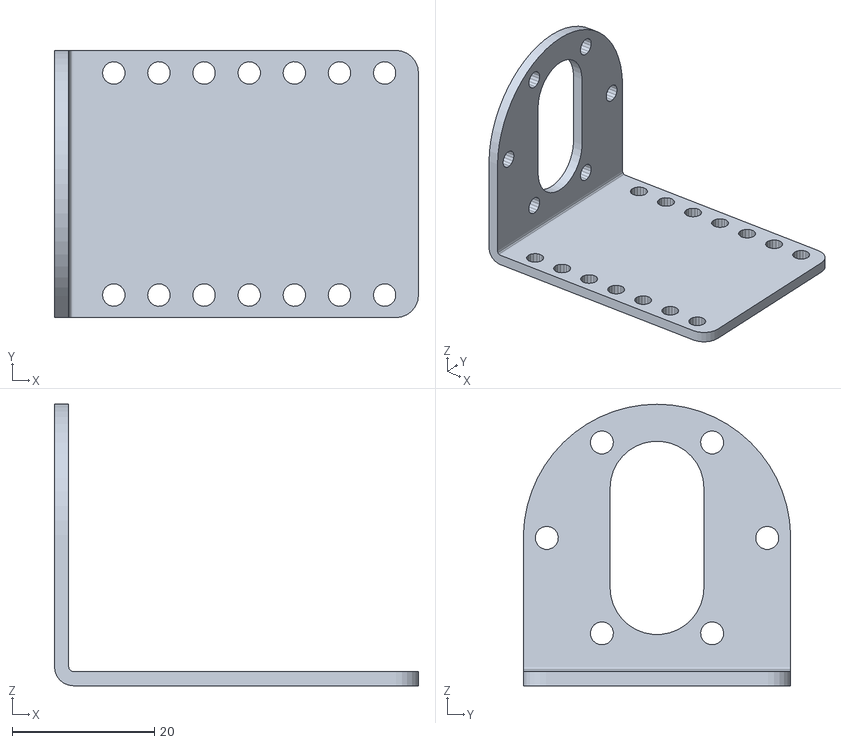
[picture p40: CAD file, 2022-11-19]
ROS/k1d_description/meshes/bracket_1.stl
51.2 x 37.6 x 39.6

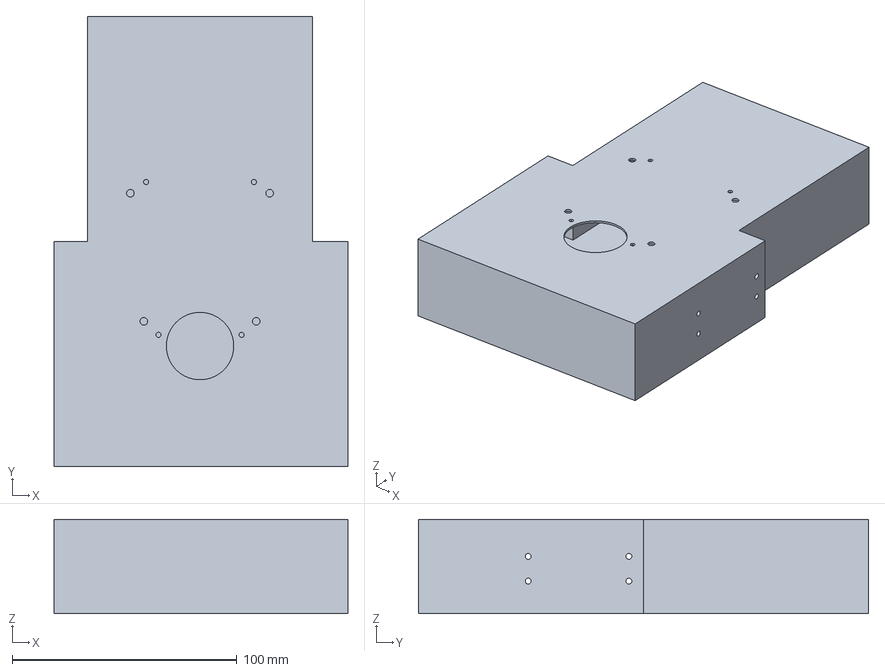
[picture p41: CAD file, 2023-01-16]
3D models and Schematics/3D models to print/Brain MDF.step
130.6 x 200.2 x 42.0 mm

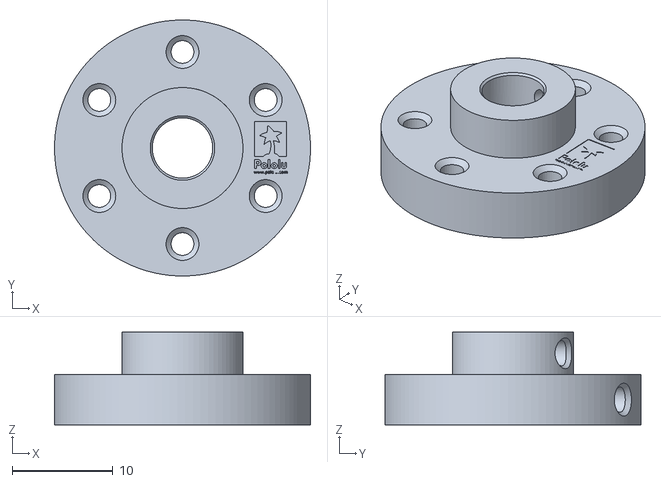
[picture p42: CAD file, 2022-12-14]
3D models and Schematics/Components (used for reference)/Motor hub.stl
25.4 x 25.4 x 9.20

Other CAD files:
Arena/Continuous_ramps_floor.stl
ROS/k1d_description/meshes/bracket_2.stl
3D models and Schematics/Components (used for reference)/LDS-01.step
Arena/Clear_floor.stl
3D models and Schematics/Components (used for reference)/AMG8833.stl
3D models and Schematics/Components (used for reference)/Aluminium motor hub.stl
3D models and Schematics/Components (used for reference)/Aproximacao bateria LiPo.step
3D models and Schematics/Components (used for reference)/CCS811.step
3D models and Schematics/Components (used for reference)/Camera USB.stl
3D models and Schematics/Components (used for reference)/Garra.step
3D models and Schematics/Components (used for reference)/Mancal.stl
Arena/Clear v3.f3d
Arena/Continuous ramps v1.f3d
Arena/Elevated ramps v1.f3d
Arena/Hurdles v1.f3d
Arena/Hurdles_floor.stl
Arena/SandGravelMulch v1.f3d
Arena/SandGravelMulch_floor.stl
Arena/Stepfields v1.f3d
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

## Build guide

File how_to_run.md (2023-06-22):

# How to run the K1D robot

## Starting robot

```cd interface```
```npm start```
```cd ..```
```cd 'Main Software'```
```cmake -S . -B build```
```cd build```
```make```
```./K1D```

## Launching Autonomous

```cd catkin_ws/src/k1d/scripts```
```roscore```
```roslaunch turtlebot3_bringup turtlebot3_remote.launch```
```roslaunch hector_mapping mapping_default.launch odom_frame:=odom```
```rviz```

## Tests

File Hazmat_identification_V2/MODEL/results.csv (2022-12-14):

epoch | train/box_loss | train/obj_loss | train/cls_loss | metrics/precision | metrics/recall | metrics/mAP_0.5 | metrics/mAP_0.5:0.95 | val/box_loss | val/obj_loss | val/cls_loss | x/lr0 | x/lr1 | x/lr2
0 | 0.072829 | 0.033523 | 0.068992 | 0.083151 | 0.2974 | 0.10945 | 0.062265 | 0.043064 | 0.014645 | 0.065305 | 0.070268 | 0.0033036 | 0.0033036
1 | 0.046887 | 0.022375 | 0.06242 | 0.33359 | 0.24544 | 0.21075 | 0.1188 | 0.037767 | 0.010339 | 0.059811 | 0.039611 | 0.0059799 | 0.0059799
2 | 0.044053 | 0.017411 | 0.056339 | 0.38538 | 0.34826 | 0.31648 | 0.16411 | 0.040441 | 0.0082924 | 0.049889 | 0.0082938 | 0.0079961 | 0.0079961
3 | 0.037805 | 0.014499 | 0.047083 | 0.55279 | 0.51552 | 0.47889 | 0.26056 | 0.032574 | 0.0070027 | 0.041041 | 0.00703 | 0.00703 | 0.00703
4 | 0.033992 | 0.013269 | 0.038382 | 0.70725 | 0.56877 | 0.65977 | 0.45606 | 0.024097 | 0.0066508 | 0.031313 | 0.00703 | 0.00703 | 0.00703
5 | 0.03063 | 0.012345 | 0.029327 | 0.74775 | 0.67206 | 0.74086 | 0.5218 | 0.022713 | 0.0064384 | 0.02425 | 0.00604 | 0.00604 | 0.00604
6 | 0.027167 | 0.010513 | 0.022288 | 0.8319 | 0.75201 | 0.82817 | 0.64213 | 0.018879 | 0.0059228 | 0.018635 | 0.00505 | 0.00505 | 0.00505
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

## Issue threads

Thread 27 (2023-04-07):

Consertar ranges da garra (pro gripper não travar)

MekhyW, 2023-04-07:

rafakatri, 2023-04-08:
MoveIt faz forward kinematics direto. Só é preciso testar se funciona com o urdf da open manipulator.

Closed 2023-06-23.

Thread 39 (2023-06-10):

ONNX runtime para modelo novo YOLOv5 (ou ao menos fazer modelo antigo rodar antes de resize)

MekhyW, 2023-06-10:
https://medium.com/mlearning-ai/detecting-objects-with-yolov5-opencv-python-and-c-c7cf13d1483c
branch yolov5-ajustes
falta consertar problema do readnetfromonnx (testar versão nova opencv 4)

Closed 2023-07-03.

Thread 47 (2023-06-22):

Testar e corrigir visualização gas e temperatura

MekhyW, 2023-06-22:

Closed 2023-06-22.

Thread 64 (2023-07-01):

Corrigir problema do lidar não girar na inicialização

MekhyW, 2023-07-01:

Closed 2023-07-03.

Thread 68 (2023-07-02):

Reverter sensor de temperatura para AMG8833

MekhyW, 2023-07-02:

Closed 2023-07-03.

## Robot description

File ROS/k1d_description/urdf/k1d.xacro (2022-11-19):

<?xml version="1.0" ?>
<robot name="k1d" xmlns:xacro="http://www.ros.org/wiki/xacro">

<xacro:include filename="$(find k1d_description)/urdf/materials.xacro" />
<xacro:include filename="$(find k1d_description)/urdf/k1d.trans" />
<xacro:include filename="$(find k1d_description)/urdf/k1d.gazebo" />
<link name="base_link">
  <inertial>
    <origin xyz="-0.000633320061717951 -0.041414084124841974 -0.011332276162165584" rpy="0 0 0"/>
    <mass value="0.8679378922144382"/>
    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
  </inertial>
  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
</link>

<link name="base_scan_1">
  <inertial>
    <origin xyz="-0.031013242986738847 0.03010215849057539 0.006905221273833313" rpy="0 0 0"/>
    <mass value="0.05487799022217015"/>
    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
  </inertial>
  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
</link>

<link name="bearing_1">
  <inertial>
    <origin xyz="-4.700706713833781e-07 0.005000307196905395 -4.6923354529115034e-07" rpy="0 0 0"/>
    <mass value="0.05425530512749553"/>
    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
  </inertial>
  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
</link>

<link name="limiter_1">
  <inertial>
    <origin xyz="0.00021788879744154987 0.0009369691662430065 0.008633565621573192" rpy="0 0 0"/>
    <mass value="0.006375075725917784"/>
    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
  </inertial>
  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
</link>

<link name="chassisback_1">
  <inertial>
    <origin xyz="-1.2436701145940895e-05 0.03463766858738379 -0.0253679156939081" rpy="0 0 0"/>
    <mass value="0.6099593335094626"/>
    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
  </inertial>
  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
</link>

<link name="bracket_1">
  <inertial>
    <origin xyz="-0.02889063899231881 -0.01561538393544995 0.006770707043989903" rpy="0 0 0"/>
    <mass value="0.04195982764049016"/>
    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
  </inertial>
  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
</link>

<link name="bracket_4">
  <inertial>
    <origin xyz="0.028890977169466116 0.015615750207864133 0.006770707043183961" rpy="0 0 0"/>
    <mass value="0.04195982764049016"/>
    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
  </inertial>
  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
</link>

<link name="bracket_3">
  <inertial>
    <origin xyz="-0.02889063896005917 0.015626470195984704 0.006770707043985354" rpy="0 0 0"/>
    <mass value="0.04195982764049016"/>
    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
  </inertial>
  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
</link>

<link name="bracket_2">
  <inertial>
    <origin xyz="0.02889097720172588 0.015615604339298622 0.006770707043178906" rpy="0 0 0"/>
    <mass value="0.04195982764049016"/>
    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
  </inertial>
  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
</link>

<link name="dcmotor_1">
  <inertial>
    <origin xyz="0.028507599418057812 -2.7385761959139443e-05 0.0068004551265215905" rpy="0 0 0"/>
    <mass value="0.45909174206904396"/>
    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
  </inertial>
  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
</link>

<link name="dcmotor_2">
  <inertial>
    <origin xyz="-0.02850726120844349 2.7606165807755878e-05 0.006800455125904808" rpy="0 0 0"/>
    <mass value="0.45909174206904396"/>
    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
  </inertial>
  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
</link>

<link name="dcmotor_3">
  <inertial>
    <origin xyz="0.028507599450317465 -2.753163052453267e-05 0.006800455126517084" rpy="0 0 0"/>
    <mass value="0.45909174206904396"/>
    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
  </inertial>
  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
</link>

<link name="dcmotor_4">
  <inertial>
    <origin xyz="-0.028507261240703193 2.7752034373065837e-05 0.006800455125909762" rpy="0 0 0"/>
    <mass value="0.45909174206904396"/>
    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
  </inertial>
  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
</link>

<link name="hub_1">
  <inertial>
    <origin xyz="0.0031138310480299386 -0.0001543860489675447 9.100569364329028e-05" rpy="0 0 0"/>
    <mass value="0.02001967132782171"/>
    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
  </inertial>
  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
</link>

<link name="hub_2">
  <inertial>
    <origin xyz="-0.003113492838516446 0.00015460645281629992 9.100569231643499e-05" rpy="0 0 0"/>
    <mass value="0.02001967132782171"/>
    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
  </inertial>
  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
</link>

<link name="hub_3">
  <inertial>
    <origin xyz="0.0031138310802898694 -0.0001545319175329657 9.100569363862387e-05" rpy="0 0 0"/>
    <mass value="0.02001967132782171"/>
    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
  </inertial>
  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
</link>

<link name="hub_4">
  <inertial>
    <origin xyz="-0.0031134928707760023 0.00015475232138174866 9.100569232154895e-05" rpy="0 0 0"/>
    <mass value="0.02001967132782171"/>
    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
  </inertial>
  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
</link>

<link name="wheel_1">
  <inertial>
    <origin xyz="-0.011849757228356753 1.8315325828188733e-07 2.629076953537812e-07" rpy="0 0 0"/>
    <mass value="2.126491898240408"/>
    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
  </inertial>
  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
</link>

<link name="wheel_2">
  <inertial>
    <origin xyz="-0.011849757196097072 3.728469279151714e-08 2.629076902745109e-07" rpy="0 0 0"/>
    <mass value="2.126491898240408"/>
    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
  </inertial>
  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
</link>

<link name="wheel_3">
  <inertial>
    <origin xyz="0.011850095437869135 3.725059061210345e-08 2.629088816027969e-07" rpy="0 0 0"/>
    <mass value="2.126491898240408"/>
    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
  </inertial>
  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
</link>

<link name="wheel_4">
  <inertial>
    <origin xyz="0.011850095405609426 1.8311915624125152e-07 2.6290888621716135e-07" rpy="0 0 0"/>
    <mass value="2.126491898240408"/>
    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
  </inertial>
  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
</link>

<link name="spacer_1">
  <inertial>
    <origin xyz="0.03099956508952051 -3.111700395755368e-07 0.01073353076646108" rpy="0 0 0"/>
    <mass value="0.002382449094157573"/>
    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
  </inertial>
  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
</link>

<link name="clawholder_1">
  <inertial>
    <origin xyz="0.031997119905123016 -0.006143865086212039 0.010024736780897991" rpy="0 0 0"/>
    <mass value="0.11911655346514588"/>
    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
  </inertial>
  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
</link>

<link name="gassensor_1">
  <inertial>
    <origin xyz="-0.004746631959460942 -0.0008000280042196398 -0.007877393733740051" rpy="0 0 0"/>
    <mass value="0.0034603887447628642"/>
    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
  </inertial>
  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
</link>

<link name="thermalsensor_1">
  <inertial>
    <origin xyz="0.009947674706848693 -0.0011020386741580346 -0.009714002418419354" rpy="0 0 0"/>
    <mass value="0.004996183093515437"/>
    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
  </inertial>
  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
</link>

<link name="battery_1">
  <inertial>
    <origin xyz="-0.05500011915754396 -0.017595185994781874 0.010103203711203074" rpy="0 0 0"/>
    <mass value="0.6140038483319866"/>
    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
  </inertial>
  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
</link>

<link name="usbhub_1">
  <inertial>
    <origin xyz="-0.050083838124938704 0.016946085208227595 0.013118894325403644" rpy="0 0 0"/>
    <mass value="0.555204593683218"/>
    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
  </inertial>
  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
</link>

<link name="DC12_W-IDLE_ALT1_1">
  <inertial>
    <origin xyz="-0.016299122954718883 0.020480802014490297 -0.011000469233539034" rpy="0 0 0"/>
    <mass value="0.33646225639068494"/>
    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
  </inertial>
  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
</link>

<link name="FR12_H101_1">
  <inertial>
    <origin xyz="-0.021000110478255726 0.020374146907254635 -4.6923355151440305e-07" rpy="0 0 0"/>
    <mass value="0.03437095087164525"/>
    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
  </inertial>
  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
</link>

<link name="ILA-A01_OPEN_1">
  <inertial>
    <origin xyz="-0.012000110474712982 0.039399195230753525 -0.006003908265283173" rpy="0 0 0"/>
    <mass value="0.13410736520700092"/>
    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
  </inertial>
  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
</link>

<link name="FR12_S101_1">
  <inertial>
    <origin xyz="-0.012000110478030184 0.002327711166216606 0.005999530766310754" rpy="0 0 0"/>
    <mass value="0.024686418261500025"/>
    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
  </inertial>
  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
</link>

<link name="FR12_H101_2">
  <inertial>
    <origin xyz="-0.021000110482432277 -0.0203238284716646 0.0014207353834639752" rpy="0 0 0"/>
    <mass value="0.03437095087164525"/>
    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
  </inertial>
  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
</link>

<link name="ILA-A02_OPEN_1">
  <inertial>
    <origin xyz="-0.012000110478114587 -0.027307262569741378 -0.004101798037027038" rpy="0 0 0"/>
    <mass value="0.09495273808046654"/>
    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
  </inertial>
  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
</link>

<link name="FR12_S102_2">
  <inertial>
    <origin xyz="-0.012000110496538735 -0.0031995611667791288 -0.005791315715793652" rpy="0 0 0"/>
    <mass value="0.01630992935911327"/>
    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
  </inertial>
  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
</link>

<link name="DC12_W-IDLE_ALT1_3">
  <inertial>
    <origin xyz="-0.0162991229786601 -0.019663116396526195 0.012401770852094388" rpy="0 0 0"/>
    <mass value="0.33646225639068494"/>
    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
  </inertial>
  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
</link>

<link name="FR12_H104_1">
  <inertial>
    <origin xyz="-0.02050011059852679 -0.022576590762154753 0.00821656608975628" rpy="0 0 0"/>
    <mass value="0.033869717896312025"/>
    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
  </inertial>
  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
</link>

<link name="camera__1__1">
  <inertial>
    <origin xyz="8.864610952068479e-06 0.019607953749089864 0.024310133593720626" rpy="0 0 0"/>
    <mass value="0.4370558986671765"/>
    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
  </inertial>
  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
</link>
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

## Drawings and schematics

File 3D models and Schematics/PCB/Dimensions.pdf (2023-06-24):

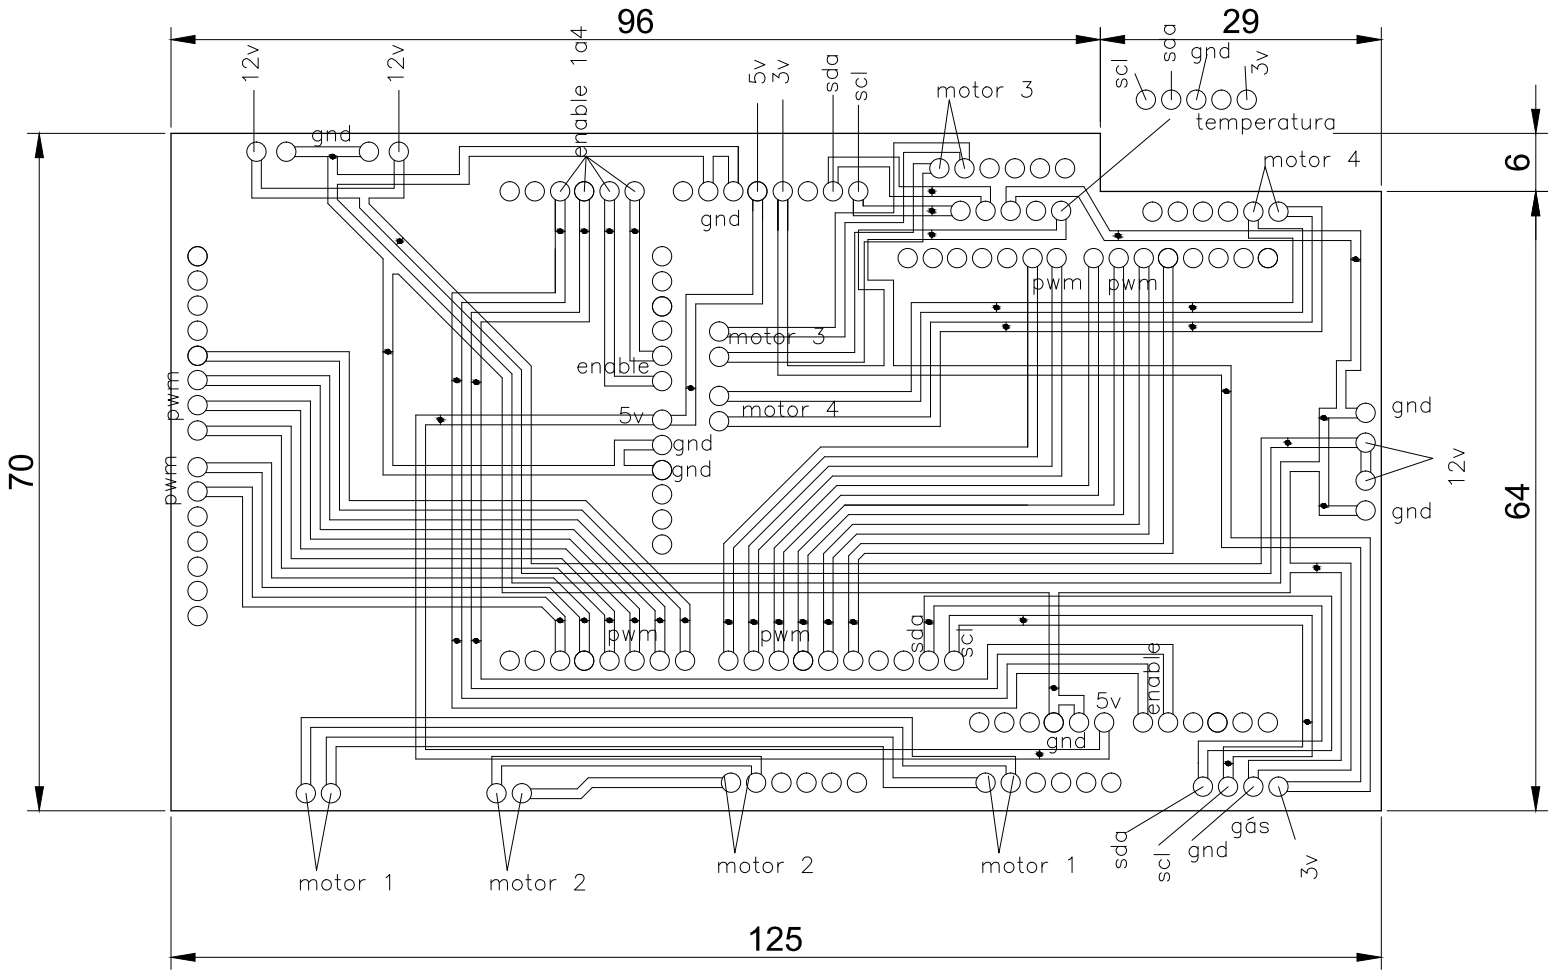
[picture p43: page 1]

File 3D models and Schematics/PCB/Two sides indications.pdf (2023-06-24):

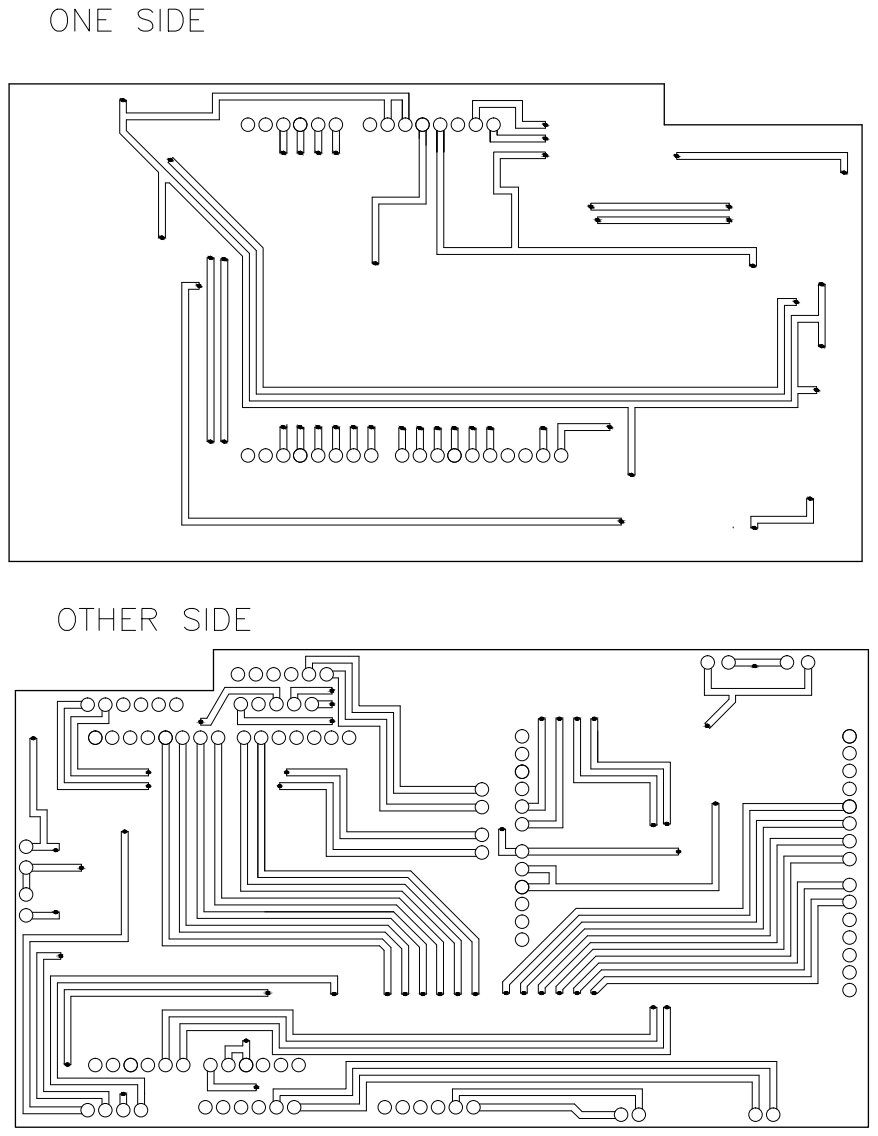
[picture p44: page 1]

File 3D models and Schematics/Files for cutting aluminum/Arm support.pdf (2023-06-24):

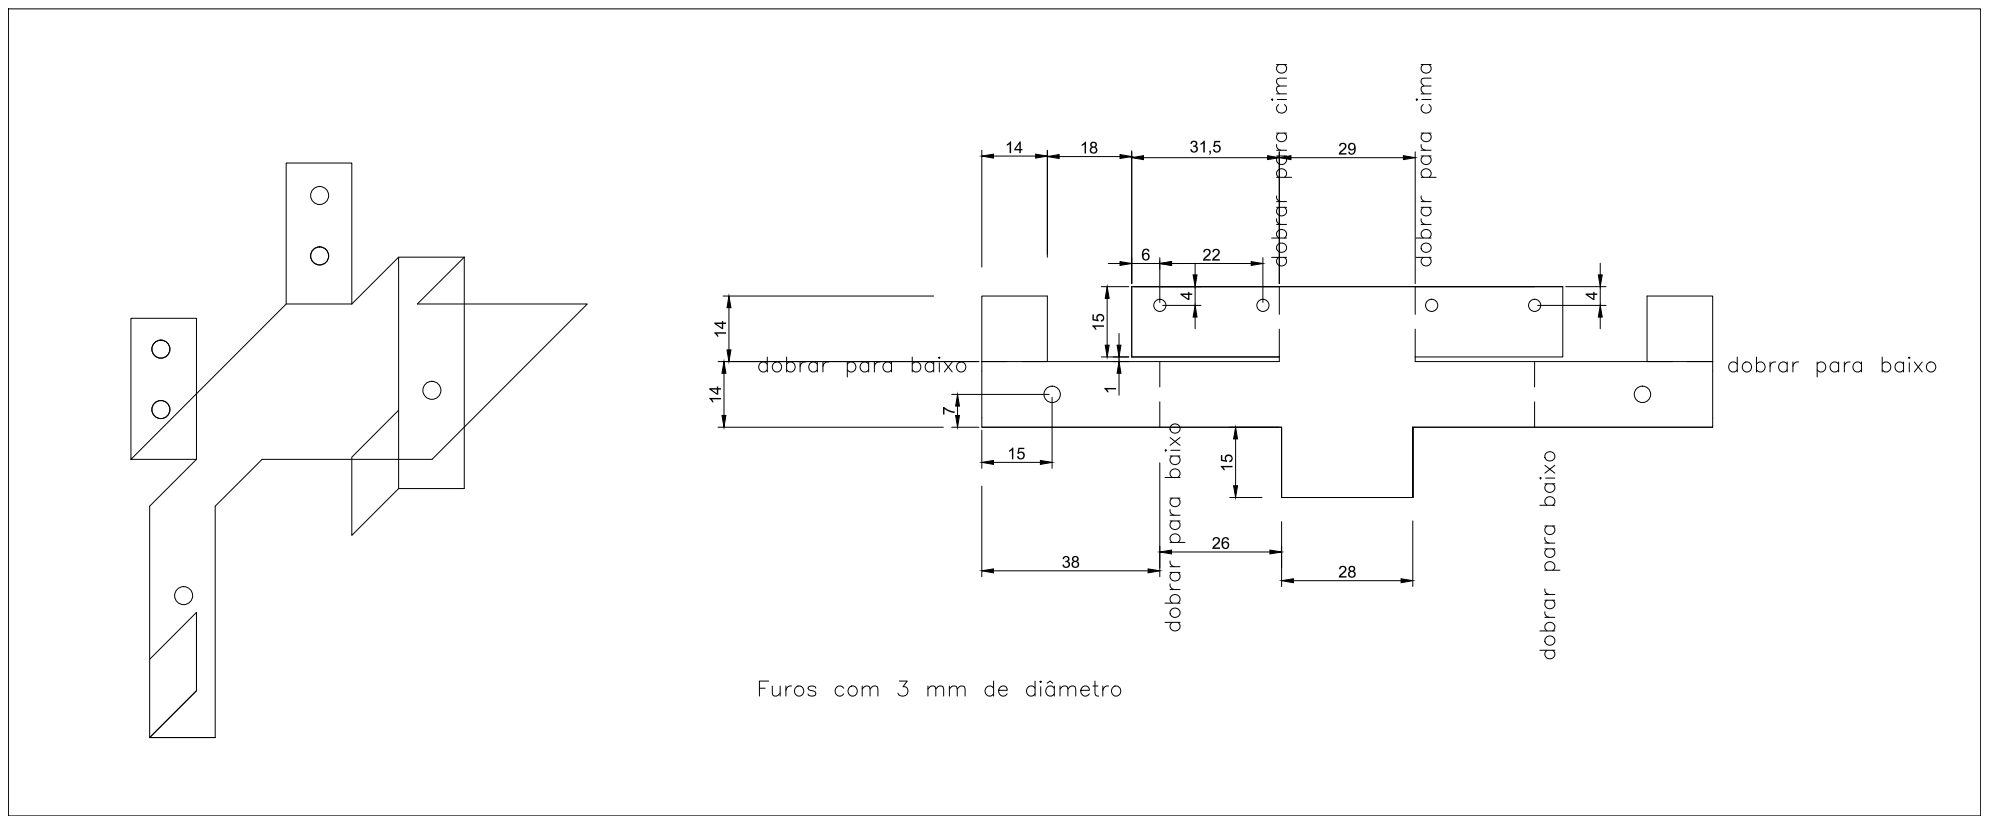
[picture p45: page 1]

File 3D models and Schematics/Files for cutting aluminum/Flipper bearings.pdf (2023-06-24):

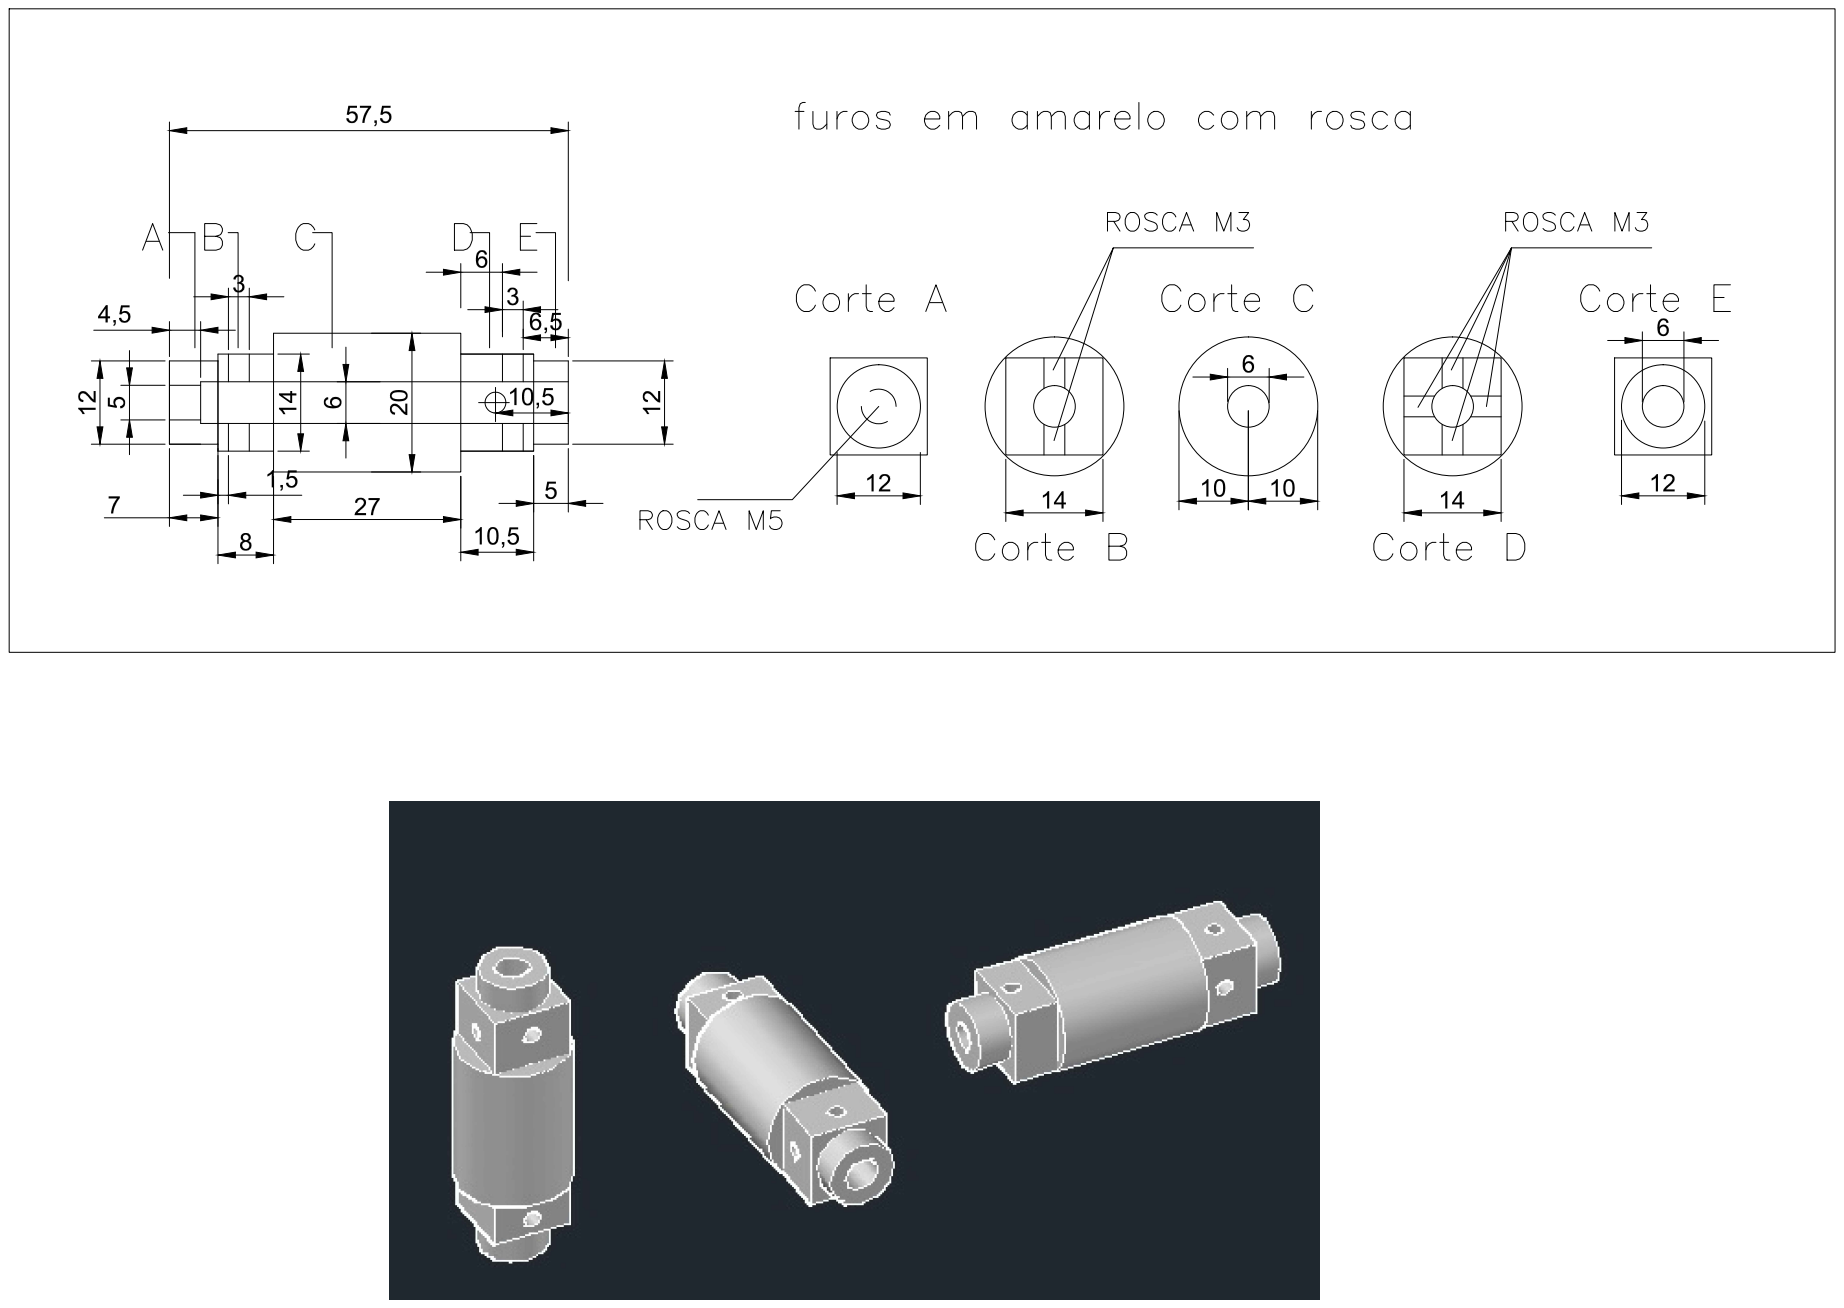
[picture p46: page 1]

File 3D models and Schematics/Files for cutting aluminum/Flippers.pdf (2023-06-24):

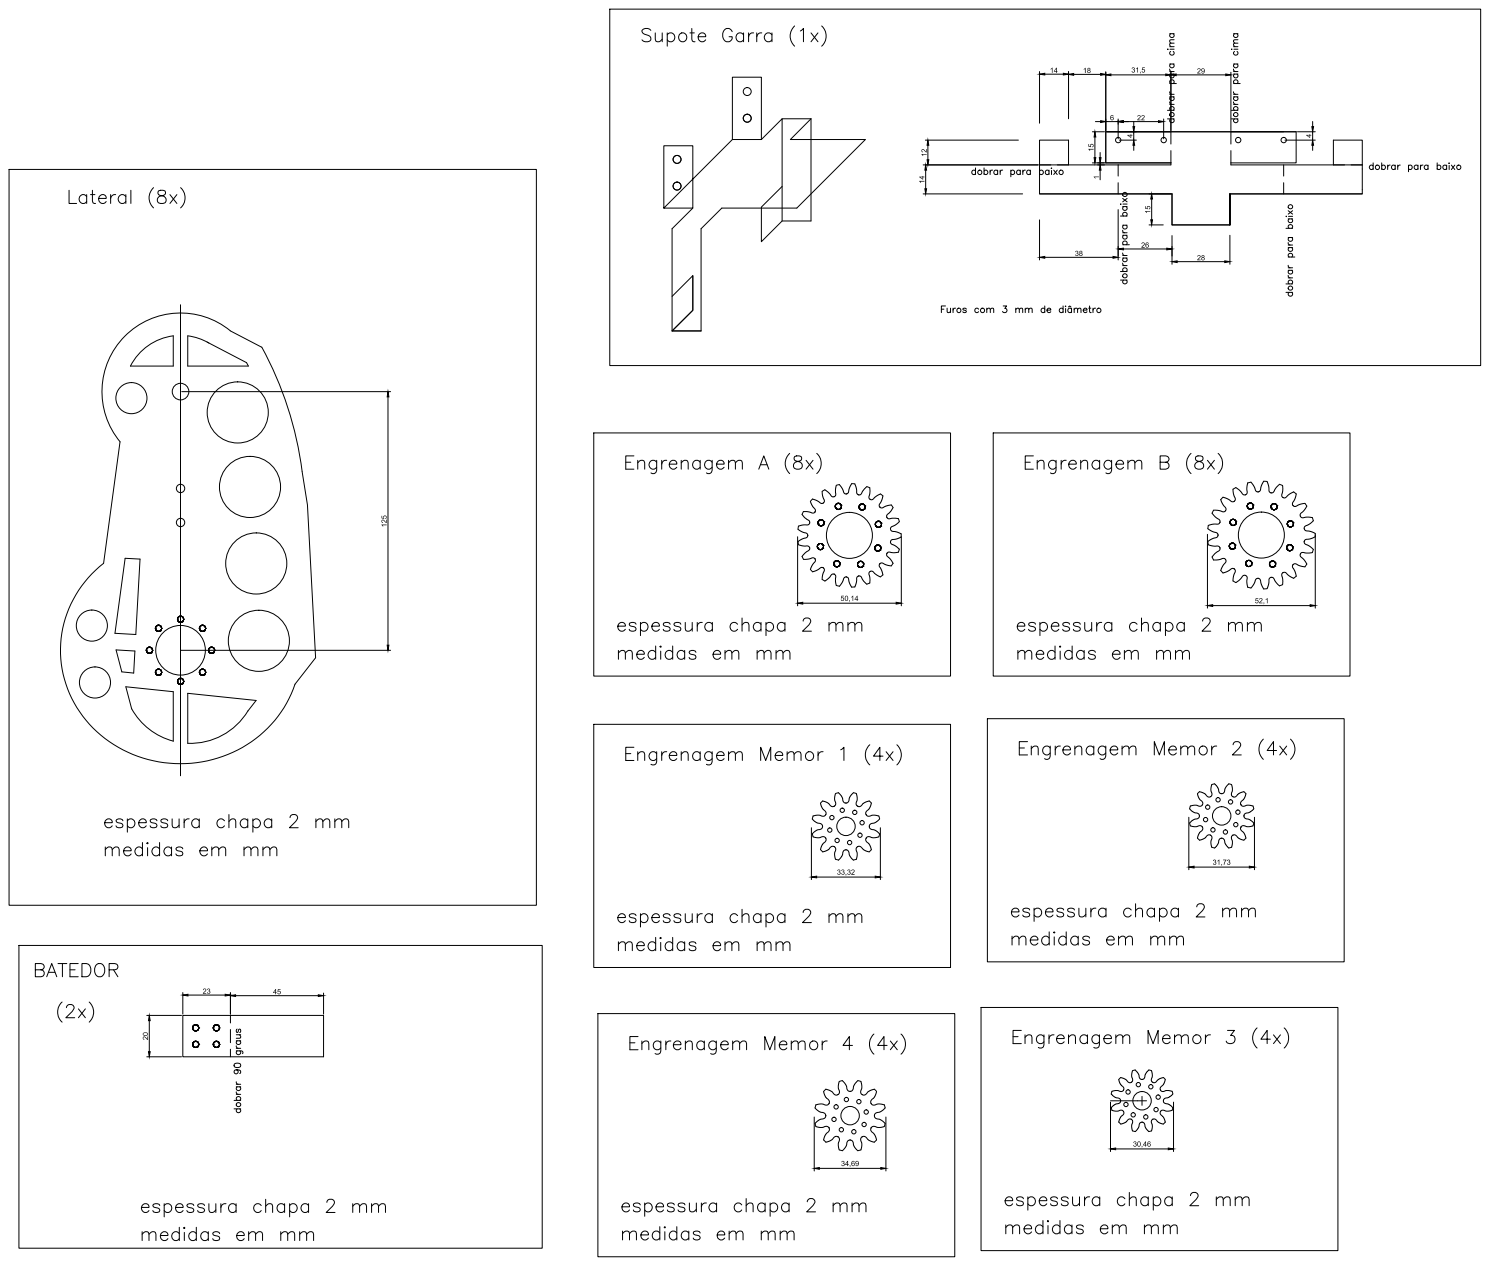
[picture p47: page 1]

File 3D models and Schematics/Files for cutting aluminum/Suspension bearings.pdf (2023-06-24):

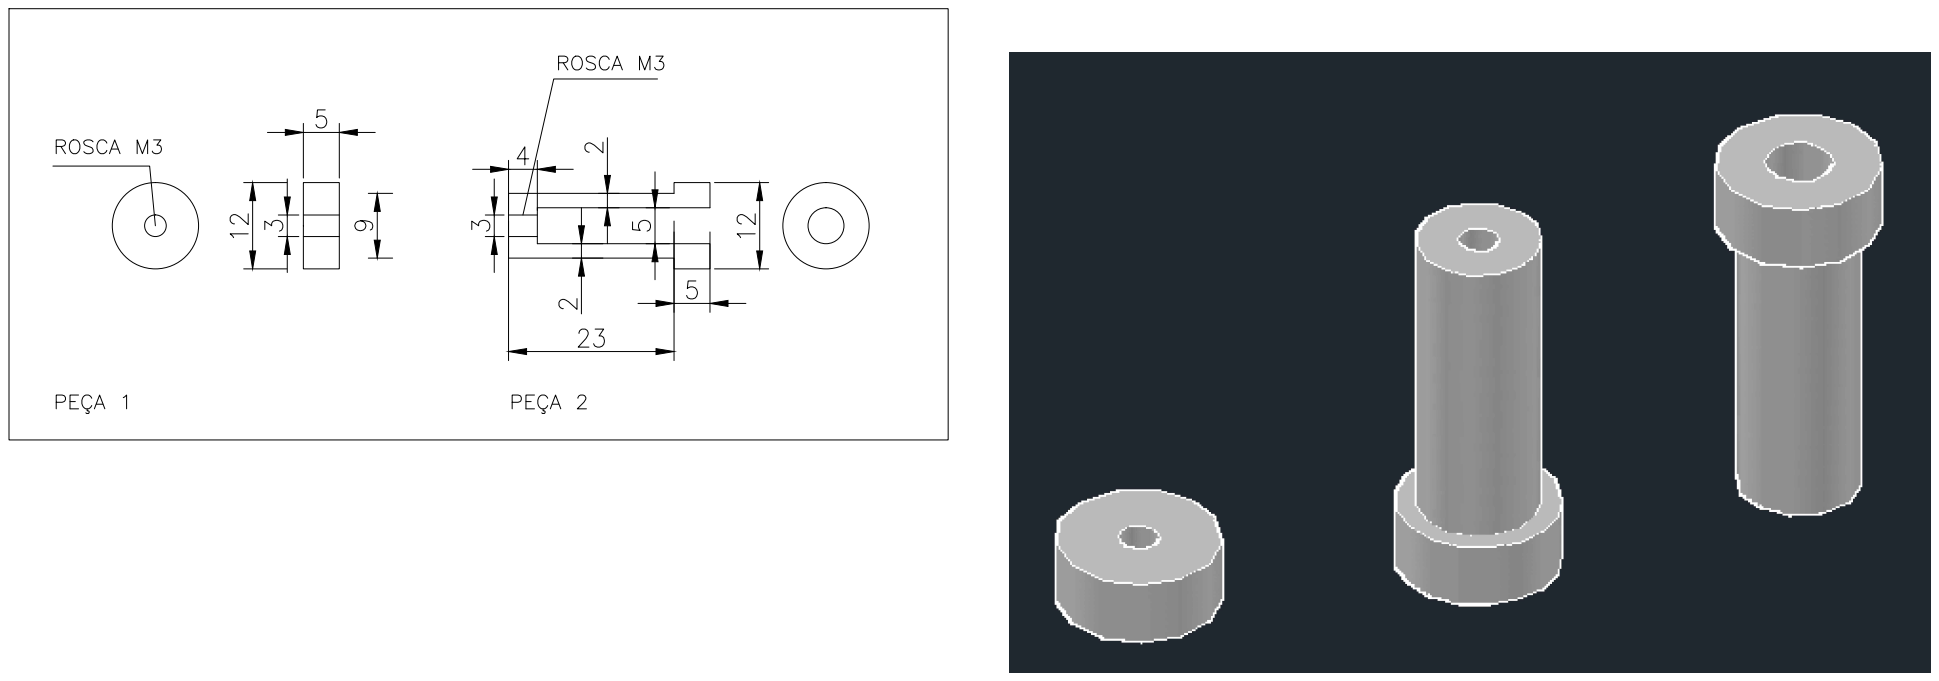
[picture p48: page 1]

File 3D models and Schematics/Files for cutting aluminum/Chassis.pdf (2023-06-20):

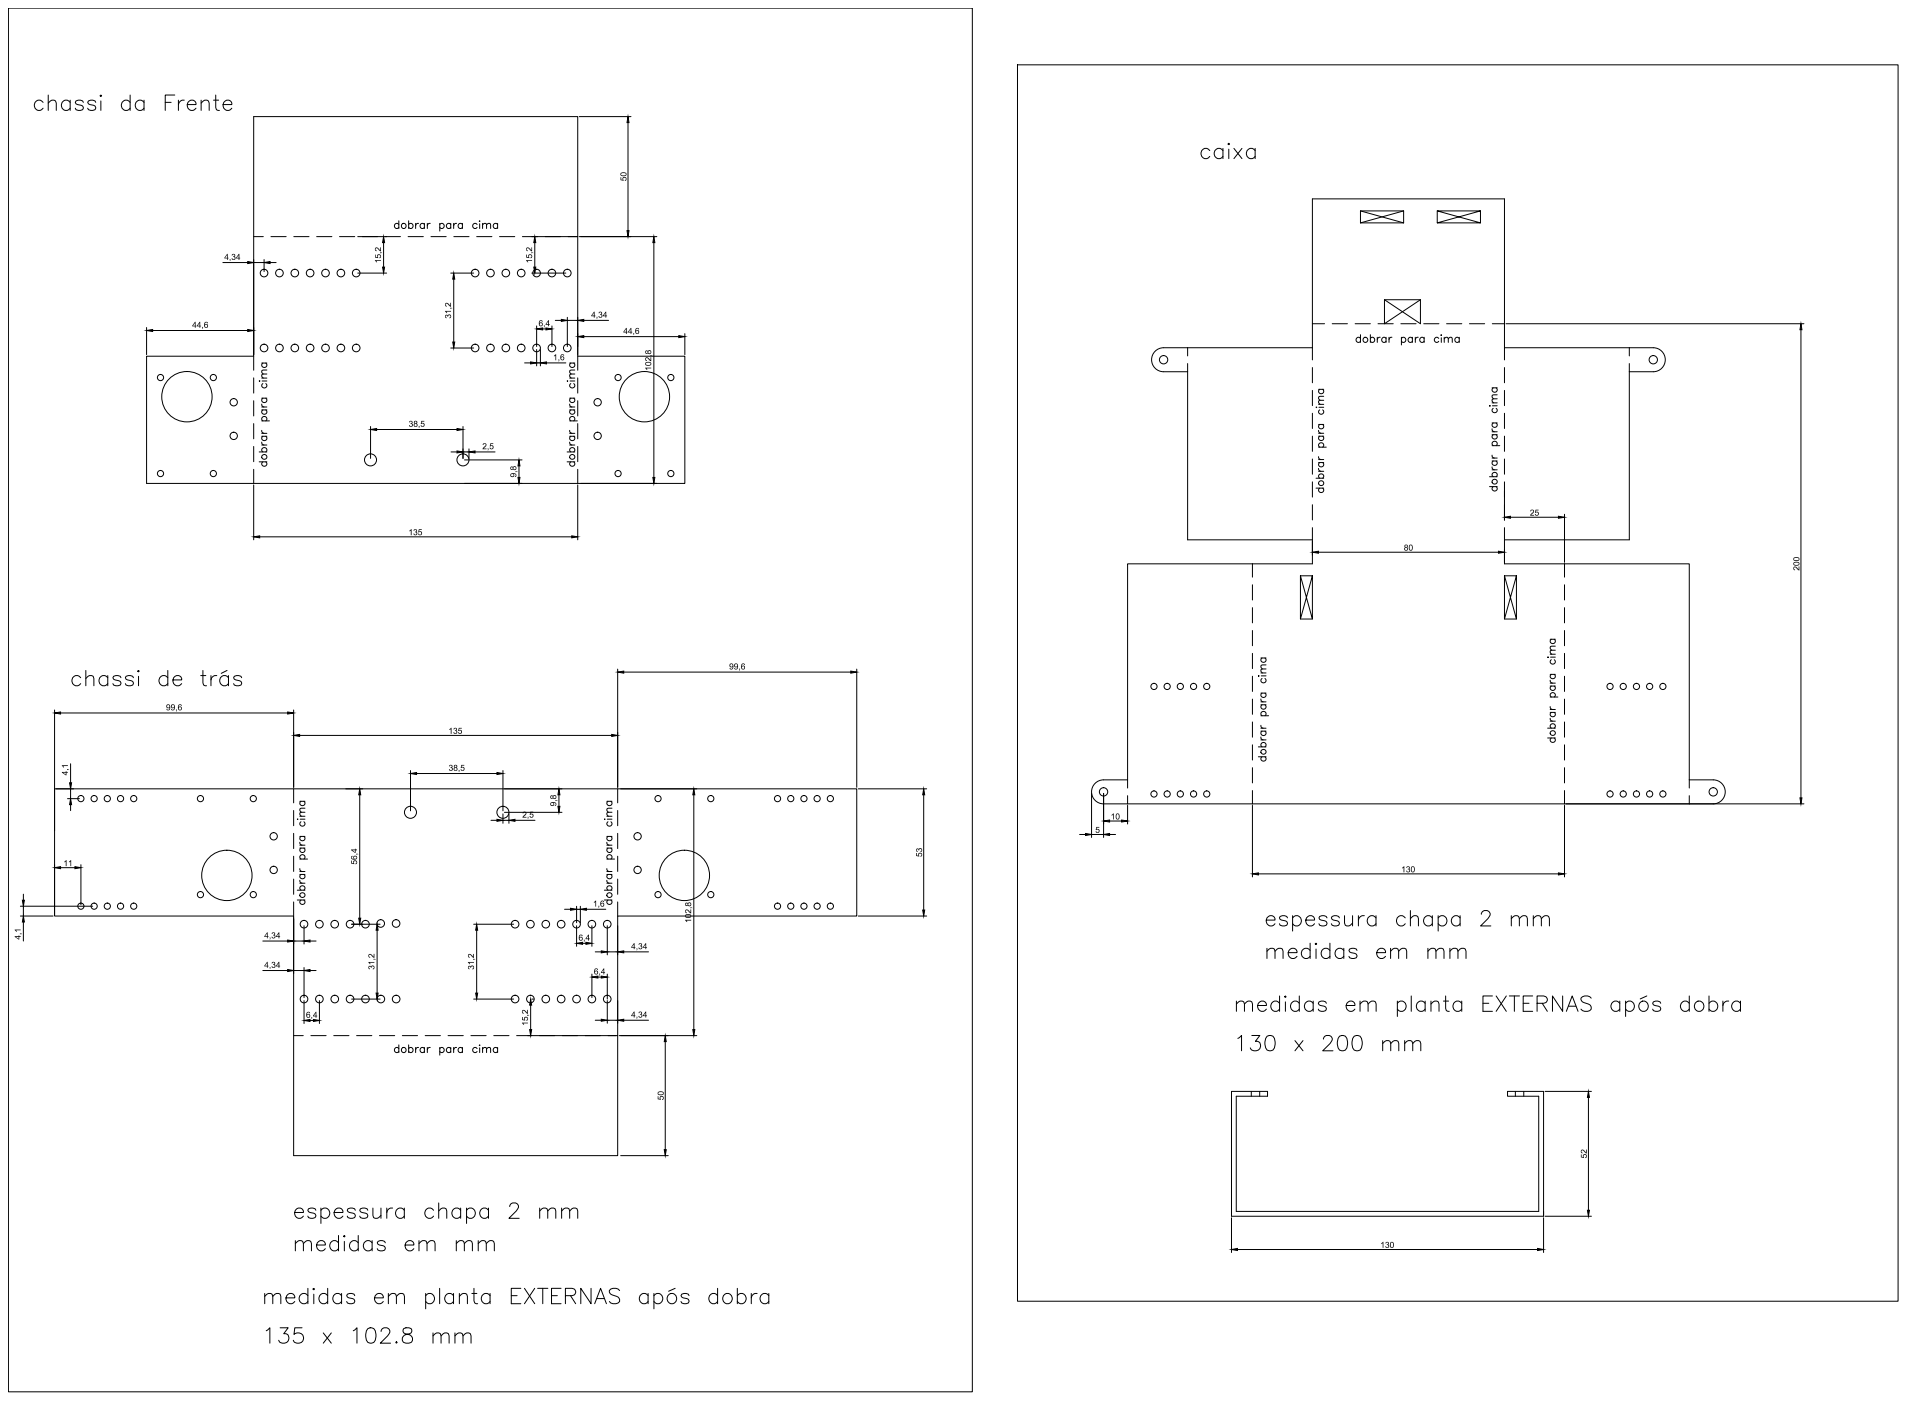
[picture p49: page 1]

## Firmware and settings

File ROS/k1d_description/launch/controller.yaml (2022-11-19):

k1d_controller:
  # Publish all joint states -----------------------------------
  joint_state_controller:
    type: joint_state_controller/JointStateController
    publish_rate: 50

  # Position Controllers --------------------------------------
  Rev4_position_controller:
    type: effort_controllers/JointPositionController
    joint: Rev4
    pid: {p: 100.0, i: 0.01, d: 10.0}
  Rev17_position_controller:
    type: effort_controllers/JointPositionController
    joint: Rev17
    pid: {p: 100.0, i: 0.01, d: 10.0}
  Rev18_position_controller:
    type: effort_controllers/JointPositionController
    joint: Rev18
    pid: {p: 100.0, i: 0.01, d: 10.0}
  Rev19_position_controller:
    type: effort_controllers/JointPositionController
    joint: Rev19
    pid: {p: 100.0, i: 0.01, d: 10.0}
  Rev20_position_controller:
    type: effort_controllers/JointPositionController
    joint: Rev20
    pid: {p: 100.0, i: 0.01, d: 10.0}
  Rev28_position_controller:
    type: effort_controllers/JointPositionController
    joint: Rev28
    pid: {p: 100.0, i: 0.01, d: 10.0}
  Rev32_position_controller:
    type: effort_controllers/JointPositionController
    joint: Rev32
    pid: {p: 100.0, i: 0.01, d: 10.0}
  Rev36_position_controller:
    type: effort_controllers/JointPositionController
    joint: Rev36
    pid: {p: 100.0, i: 0.01, d: 10.0}
  Rev42_position_controller:
    type: effort_controllers/JointPositionController
    joint: Rev42
    pid: {p: 100.0, i: 0.01, d: 10.0}

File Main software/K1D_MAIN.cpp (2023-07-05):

#include <iostream>
#include <string>
#include <opencv4/opencv2/opencv.hpp>
#include "ROS_communication.h"
#include "Gamepad_controller.h"
#include "Claw.h"
#include "Thermal_gas.h"
#include "QR_read.h"
#include "Motion_detection.h"
#include "Hazmat_detection.h"
using namespace std;
using namespace cv;
int resolution_horizontal = 800;
int resolution_vertical = 600;
VideoCapture captureA;
VideoCapture captureB;
VideoCapture camera;
Mat frameCam = Mat::zeros(resolution_horizontal, resolution_vertical, CV_8UC3);
int captureA_index = 0;
int captureB_index = 1;
Mat frameA = Mat::zeros(resolution_horizontal, resolution_vertical, CV_8UC3);
Mat frameB = Mat::zeros(resolution_horizontal, resolution_vertical, CV_8UC3);
Mat webcam_image = Mat::zeros(2 * resolution_horizontal, resolution_vertical, CV_8UC3);

void openCamera()
{
    int is_working = 1;
    int dev_port = 0;
    while (is_working) {
        camera = VideoCapture(dev_port);
        if (!camera.isOpened()) {
            is_working = 0;
		}
        else {
            bool is_reading =  camera.read(frameCam);
            double w = camera.get(3);
            double h = camera.get(4);
            if (is_reading) {
				if (w == 1920 && h == 1080) {
					captureA_index = dev_port;
				}
				else if (w == 2304 && h == 1536) {
					captureB_index = dev_port;
				}
			}
		}
        dev_port += 2;
	}
	camera.release();
	captureA.open(captureA_index);
	captureB.open(captureB_index);
	captureA.set(CAP_PROP_FPS, 30);
	captureB.set(CAP_PROP_FPS, 30);
}

float mapPwm(float n, float fromLow, float fromHigh, float outLow, float outHigh) {
    float normalized = (n - fromLow) / (fromHigh - fromLow);
    return outLow + normalized * (outHigh - outLow);
}

void MoveManual()
{
	PublishOpenCR(gamepad_command, gamepad_value_1, gamepad_value_2);
}

void MoveAutonomous()
{
	const float wheelBase = 0.12;
	const float wheelRadius = 0.055;
	const float fromLow = -3 / (2*wheelRadius);
	const float fromHigh = 3 / (2*wheelRadius);
	const float toLow = -200;
	const float toHigh = 200;
	float l = ((2*cmdvel_linear_x) - (cmdvel_angular_z*wheelBase)) / (2*wheelRadius);
  	float r = ((2*cmdvel_linear_x) + (cmdvel_angular_z*wheelBase)) / (2*wheelRadius);
	uint16_t pwm_l = mapPwm(l, fromLow, fromHigh, toLow, toHigh);
	uint16_t pwm_r = mapPwm(r, fromLow, fromHigh, toLow, toHigh);
	PublishOpenCR("MotorsMove", pwm_l, pwm_r);
}

void checkUserInput()
{
	cout << gamepad_command << " " << to_string(gamepad_value_1) << " " << to_string(gamepad_value_2) << "\n";
	if (gamepad_command == "RaiseFrontFlippers")
		RaiseFrontFlippers();
	else if (gamepad_command == "LowerFrontFlippers")
		LowerFrontFlippers();
	else if (gamepad_command == "RaiseBackFlippers")
		RaiseBackFlippers();
	else if (gamepad_command == "LowerBackFlippers")
		LowerBackFlippers();
	else if (gamepad_command == "LowerIndividualFlipper")
		LowerFlipper();
	else if (gamepad_command == "RaiseIndividualFlipper")
		RaiseFlipper();
	else if (gamepad_command == "ClawRetract")
		ClawRetract();
	else if (gamepad_command == "First+" && dexterity_mode)
		FirstPlus();
	else if (gamepad_command == "First-" && dexterity_mode)
		FirstMinus();
	else if (gamepad_command == "Second+" && dexterity_mode)
		SecondPlus();
	else if (gamepad_command == "Second-" && dexterity_mode)
		SecondMinus();
	else if (gamepad_command == "ClawOpen" && dexterity_mode)
		ClawOpen();
	else if (gamepad_command == "ClawClose" && dexterity_mode)
		ClawClose();
	else if (gamepad_command == "Third+" && dexterity_mode)
		ThirdPlus();
	else if (gamepad_command == "Third-" && dexterity_mode)
		ThirdMinus();
	else if (gamepad_command == "OpenGripper" && dexterity_mode)
		ClawOpen();
	else if (gamepad_command == "CloseGripper" && dexterity_mode)
		ClawClose();
	else if (!autonomous_mode && !gamepad_command.empty())
		MoveManual();
	else if (autonomous_mode)
		MoveAutonomous();
}

void captureFrame()
{
	Mat frameA_local;
	Mat frameB_local;
	bool retA = captureA.read(frameA_local);
	bool retB = captureB.read(frameB_local);
	if (retA) {
		frameA = frameA_local;
	}
	else {
		try
		{
			captureA.release();
			captureA.open(captureA_index);
			captureA.set(CAP_PROP_FPS, 30);
		}
		catch(const std::exception& e)
		{
			std::cerr << e.what() << '\n';
		}
	}
	if (retB) {
		frameB = frameB_local;
	}
	else {
		try
		{
			captureB.release();
			captureB.open(captureB_index);
			captureB.set(CAP_PROP_FPS, 30);
		}
		catch(const std::exception& e)
		{
			std::cerr << e.what() << '\n';
		}
	}
	if (frameA.rows > frameB.rows)
		resize(frameB, frameB, Size(frameA.cols, frameA.rows), INTER_NEAREST);
	else if (frameA.rows < frameB.rows)
		resize(frameA, frameA, Size(frameB.cols, frameB.rows), INTER_NEAREST);
	hconcat(frameA, frameB, webcam_image);
}

void checkSensorsFeed()
{
	ReadOpenCR();
	UpdateGas(current_gas);
	UpdateThermal(current_temperature);
	captureFrame();
	if (qr_detection)
		webcam_image = ReadQR(webcam_image);
	if (hazmat_detection)
		webcam_image = DetectHazmat(webcam_image);
	if (motion_detection)
		webcam_image = DetectMotionAbsdiff(webcam_image);
	resize(webcam_image, webcam_image, Size(2*resolution_horizontal, resolution_vertical), INTER_NEAREST);
}


void setup(int argc, char** argv) 
{
	system("sudo echo 'k1d'");
	system("gnome-terminal -- play '|rec --buffer 512 -d'");
	ConnectROS(argc, argv);
	namedWindow("K1D");
	namedWindow("CO2");
	namedWindow("Thermal");
	openCamera();
	InitializeQR();
	InitializeHazmat();
}


void loop()
{
	if (SDL_GameControllerGetPlayerIndex(gGameController) < 1)
		InitializeGamepad();
	UpdateGamepadInput();
	checkUserInput();
	checkSensorsFeed();
	imshow("K1D", webcam_image);
	imshow("CO2", gas_image);
	imshow("Thermal", thermal_image);
	waitKey(1);
}


int main(int argc, char** argv)
{
	setup(argc, argv);
	while (true)
	{
		try {loop();}
		catch (const std::exception& e){cout << e.what() << endl;}
		catch (ros::Exception &e ){cout << e.what() << endl;}
		catch (const cv::Exception& e){cout << e.what() << endl;}
		catch (...){cout << "Unknown error occurred!" << endl;}
	}
	return 0;
}

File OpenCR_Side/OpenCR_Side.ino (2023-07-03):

// K1D Robot (Redox 2)
// Insper Dynamics
#include <ros.h>
#include <std_msgs/String.h>
#include <std_msgs/Int16.h>
#include <std_msgs/UInt16.h>
#include <std_msgs/Int32.h>
#include <std_msgs/Int32MultiArray.h>
#include <std_msgs/Bool.h>
#include <std_msgs/Float32MultiArray.h>
#include "Sensors.h"
#include "Motors.h"
#include "Servos.h"

String current_command = "";
int current_value_1 = 0;
int current_value_2 = 0;
bool sensor_mode = false;
std_msgs::UInt16 gas;
std_msgs::Float32MultiArray temperature;



void commandCallback(const std_msgs::String& command){
  current_command = command.data;
}
void value1Callback(const std_msgs::Int16& value1){
  current_value_1 = value1.data;
}
void value2Callback(const std_msgs::Int16& value2){
  current_value_2 = value2.data;
}
void jointsCallback(const std_msgs::Int32MultiArray& joint_msg){
  ControlJointDynamixel(joint_msg.data);
}
void sensorCallback(const std_msgs::Bool& sensor_msg){
  sensor_mode = sensor_msg.data;
}

ros::NodeHandle nodehandle;
ros::Publisher pub_temperature("temperature", &temperature);
ros::Publisher pub_gas("gas", &gas);
ros::Subscriber<std_msgs::String> sub_command("arduino_command", commandCallback);
ros::Subscriber<std_msgs::Int16> sub_value_1("arduino_value_1", value1Callback);
ros::Subscriber<std_msgs::Int16> sub_value_2("arduino_value_2", value2Callback);
ros::Subscriber<std_msgs::Bool> sub_sensor("sensor_mode", sensorCallback);

void ControlMotors(String command, int command_parameter_1, int command_parameter_2) {
  if (command == "MotorsMove"){
    Move(command_parameter_1, command_parameter_2);
  }
  else if (command == "MotorsStop"){
    MotorsStop();
  }
  else if (command == "RaiseFrontFlippers"){
    RaiseFrontFlipper(command_parameter_1);
  }
  else if (command == "RaiseBackFlippers"){
    RaiseBackFlipper(command_parameter_1);
  }
  else if (command == "LowerFrontFlippers"){
    LowerFrontFlipper(command_parameter_1);
  }
  else if (command == "LowerBackFlippers"){
    LowerBackFlipper(command_parameter_1);
  }
  else if (command == "LowerIndividualFlipper"){
    LowerFlipper(command_parameter_1, command_parameter_2);
  }
  else if (command == "RaiseIndividualFlipper"){
    RaiseFlipper(command_parameter_1, command_parameter_2);
  }
  else if (command == "ClawOpen"){
    OpenGripper(command_parameter_1);
  }
  else if (command == "ClawClose"){
    CloseGripper(command_parameter_1);
  }
  else if (command == "First+"){
    FirstPlus(command_parameter_1);
  }
  else if (command == "First-"){
    FirstMinus(command_parameter_1);
  }
  else if (command == "Second+"){
    SecondPlus(command_parameter_1);
  }
  else if (command == "Second-"){
    SecondMinus(command_parameter_1);
  }
  else if (command == "Third+"){
    ThirdPlus(command_parameter_1);
  }
  else if (command == "Third-"){
    ThirdMinus(command_parameter_1);
  }
  else if (command == "ClawRetract"){
    ClawRetract();
  }
}

void setup() {
  MotorsInitialize();
  SensorsInitialize();
  ServosInitialize();
  nodehandle.getHardware()->setBaud(115200);
  nodehandle.initNode();
  temperature.layout.dim[0].label = "temperature";
  temperature.layout.dim[0].size = AMG88xx_PIXEL_ARRAY_SIZE;
  temperature.layout.dim[0].stride = AMG88xx_PIXEL_ARRAY_SIZE;
  temperature.layout.data_offset = 0;
  temperature.data = (float *)malloc(sizeof(float)*AMG88xx_PIXEL_ARRAY_SIZE);
  nodehandle.advertise(pub_temperature);
  nodehandle.advertise(pub_gas);
  nodehandle.subscribe(sub_command);
  nodehandle.subscribe(sub_value_1);
  nodehandle.subscribe(sub_value_2);
  nodehandle.subscribe(sub_sensor);
}

void loop() {
  if (sensor_mode) {
    ReadSensors();
    temperature.data_length = AMG88xx_PIXEL_ARRAY_SIZE;
    for (int i=0; i < AMG88xx_PIXEL_ARRAY_SIZE; i++) {
      temperature.data[i] = amg8833_pixels[i];
    }
    gas.data = CO2level;
    pub_temperature.publish(&temperature);
    pub_gas.publish(&gas);
  }
  nodehandle.spinOnce();
  delay(1);
  ControlMotors(current_command, current_value_1, current_value_2);
}

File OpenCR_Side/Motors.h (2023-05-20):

#define enableA A0
#define enableB A1
#define enableC A2
#define enableD A3
#define motorUL 9
#define motorULdirA 10
#define motorULdirB 12
#define motorLL 11
#define motorLLdirA 13
#define motorLLdirB 8
#define motorLR 6
#define motorLRdirA 3
#define motorLRdirB 4
#define motorUR 5
#define motorURdirA 2
#define motorURdirB 7

void MotorsRelease(){
  digitalWrite(motorULdirA, LOW);
  digitalWrite(motorULdirB, LOW);
  digitalWrite(motorURdirA, LOW);
  digitalWrite(motorURdirB, LOW);
  digitalWrite(motorLLdirA, LOW);
  digitalWrite(motorLLdirB, LOW);
  digitalWrite(motorLRdirA, LOW);
  digitalWrite(motorLRdirB, LOW);
}
void MotorsStop(){
  digitalWrite(motorULdirA, HIGH);
  digitalWrite(motorULdirB, HIGH);
  digitalWrite(motorURdirA, HIGH);
  digitalWrite(motorURdirB, HIGH);
  digitalWrite(motorLLdirA, HIGH);
  digitalWrite(motorLLdirB, HIGH);
  digitalWrite(motorLRdirA, HIGH);
  digitalWrite(motorLRdirB, HIGH);
}

void MotorsInitialize(){
  pinMode(enableA, OUTPUT);
  pinMode(enableB, OUTPUT);
  pinMode(enableC, OUTPUT);
  pinMode(enableD, OUTPUT);
  digitalWrite(enableA, HIGH);
  digitalWrite(enableB, HIGH);
  digitalWrite(enableC, HIGH);
  digitalWrite(enableD, HIGH);
  pinMode(motorUL, OUTPUT);
  pinMode(motorULdirA, OUTPUT);
  pinMode(motorULdirB, OUTPUT);
  pinMode(motorUR, OUTPUT);
  pinMode(motorURdirA, OUTPUT);
  pinMode(motorURdirB, OUTPUT);
  pinMode(motorLL, OUTPUT);
  pinMode(motorLLdirA, OUTPUT);
  pinMode(motorLLdirB, OUTPUT);
  pinMode(motorLR, OUTPUT);
  pinMode(motorLRdirA, OUTPUT);
  pinMode(motorLRdirB, OUTPUT);
  MotorsRelease();
}

void URForward(){
  digitalWrite(motorURdirA, HIGH);
  digitalWrite(motorURdirB, LOW);
}
void URBackwards(){
  digitalWrite(motorURdirA, LOW);
  digitalWrite(motorURdirB, HIGH);
}
void ULForward(){
  digitalWrite(motorULdirA, HIGH);
  digitalWrite(motorULdirB, LOW);
}
void ULBackwards(){
  digitalWrite(motorULdirA, LOW);
  digitalWrite(motorULdirB, HIGH);
}
void LRForward(){
  digitalWrite(motorLRdirA, HIGH);
  digitalWrite(motorLRdirB, LOW);
}
void LRBackwards(){
  digitalWrite(motorLRdirA, LOW);
  digitalWrite(motorLRdirB, HIGH);
}
void LLForward(){
  digitalWrite(motorLLdirA, HIGH);
  digitalWrite(motorLLdirB, LOW);
}
void LLBackwards(){
  digitalWrite(motorLLdirA, LOW);
  digitalWrite(motorLLdirB, HIGH);
}

void Move(int speedL, int speedR){
  if(speedL > 0){
    ULForward();
    LLForward();
  }
  else {
    ULBackwards();
    LLBackwards();
  }
  if(speedR > 0){
    URForward();
    LRForward();
  }
  else {
    URBackwards();
    LRBackwards();
  }
  analogWrite(motorUL, constrain(abs(speedL), 0, 255));
  analogWrite(motorLL, constrain(abs(speedL), 0, 255));
  analogWrite(motorUR, constrain(abs(speedR), 0, 255));
  analogWrite(motorLR, constrain(abs(speedR), 0, 255));
}

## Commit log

2022-08-12 erros e soluções
    [RedoxNG v1.f3d, erros e soluções.xlsx]
2022-08-19 Renamed 3d file
    [K1D v5.f3z, RedoxNG v1.f3d]
2022-08-30 Copied low level code and i2c_scanner from Redox
2022-08-30 Ported Fusion 360 CAD to Siemens NX
    [Body10C1_obj.prt, Body10_obj.prt, Body112_obj.prt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]
2022-08-31 Create Insper Dynamics - Tela de Controle do K1D.fig
2022-09-01 2 USB cameras instead of 360
    [Body10C1_obj.prt, Body10_obj.prt, Body112_obj.prt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]
2022-09-05 2 USB cameras (opencv part)
2022-09-06 Update Insper Dynamics - Tela de Controle do K1D.fig
2022-09-06 Mode switches via ros topic bools
2022-09-13 Encoders.h and IMU.h
2022-11-05 Arena models
    [Clear v3.f3d, Continuous ramps v1.f3d, Elevated ramps v1.f3d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]
2022-11-10 Added OpenManipulator to CAD
    [Body10C1_obj.prt, Body10C2_obj.prt, Body10C3_obj.prt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]
2022-11-19 Prototype URDF
    [DC12_STD_2.stl, DC12_W-IDLE_ALT1_1.stl, DC12_W-IDLE_ALT1_2.stl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]
2022-11-20 hconcat working, fixed bugs
    [K1D_MAIN.cpp]
2022-11-21 Arena stl files
    [Clear.stl, Continuous_ramps.stl, Elevated_ramps.stl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]
2022-11-22 fixed some parameters autonomous (lidar interpretation still seems to be erroneous)
2022-12-12 Separated floor and walls of arena STLs
    [Clear.stl, Clear_floor.stl, Continuous_ramps.stl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]
2022-12-14 New hazmat model results
    [results.csv]
2022-12-14 Preparing for new CAD
    [AMG8833.stl, Aluminium motor hub.stl, Aproximacao bateria LiPo.step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]
2023-01-12 Claw controller + lidar updates on launch file
2023-01-16 New CAD
    [AMG8833.stl, Aluminium motor hub.stl, Aproximacao bateria LiPo.step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]
2023-01-17 Separated thread support pieces
    [Thread Support.step, ThreadSupport_face.stl, ThreadSupport_spreader.stl]
2023-01-17 ThreadSupport 4mm hole
    [ThreadSupport_face.stl, ThreadSupport_spreader.stl]
2023-02-09 Wood top and bottom DXF files
    [mdf_bottom.dxf, mdf_top.dxf]
2023-02-15 Fixed bugs of sensors OpenCR_Side
    this part of code still has compilation bugs regarding dynamixels
    [OpenCR_Side.ino, Servos.h]
2023-03-21 Openmanipulator URDF (original)
    [materials.xacro, open_manipulator.gazebo.xacro, open_manipulator.transmission.xacro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]
2023-04-06 Moved claw movement functions to Claw.h
2023-04-11 dynamixel_connector_flippers 3D model
    [ThreadSupport_spreader.stl, dynamixel_connector_flippers.stl]
2023-04-12 Fixed motor pins (all working this time)
    [Motors.h, Test_motors.ino]
2023-04-21 Create engrenagem menor estudo 5 mm - r0 - 3D.stl
    [engrenagem menor estudo 5 mm - r0 - 3D.stl]
2023-04-21 Fixing bugs flippers opencr_side
    [OpenCR_Side.ino, Servos.h]
2023-04-21 Removed calls to unused IMU
2023-04-25 Main Software flippers + motors working
    [Gamepad_controller.h, K1D_MAIN.cpp]
2023-04-25 OpenCR-side flippers + motors working
    [OpenCR_Side.ino]
2023-04-27 Create engrenagem menor estudo 5 mm - r2 - 3D v1.stl
    [engrenagem menor estudo 5 mm - r2 - 3D v1.stl]
2023-05-02 Claw 1.0 working
2023-05-18 Temporarily rolling back yolo model
    [yolov3-tiny.cfg]
2023-06-09 optical flow a disponivel
2023-06-16 delta fixed 2: a
    [Gamepad_controller.h]
2023-06-20 Updated CAD files
    [AMG8833.stl, Aluminium motor hub.stl, Aproximacao bateria LiPo.step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]
2023-06-24 PDFs of PCB
2023-06-26 camera index + hector order
2023-06-26 autonomous - move flippers automatically to remove blind spot
    [OpenCR_Side.ino, Servos.h]
2023-06-27 sdl macro mode switch working
2023-07-01 new thernal sensor
2023-07-01 sensor mode
2023-07-02 cameras fail safe
2023-07-03 cameras failsafe
2023-07-03 Revert temperature imager
2023-07-03 sensor mode is back
2023-07-03 fix type cast bug
    [Thermal_gas.h]
2023-07-05 get camera idx
